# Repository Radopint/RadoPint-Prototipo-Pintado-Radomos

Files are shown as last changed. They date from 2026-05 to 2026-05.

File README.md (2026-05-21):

# RadoPint - Prototipo a escala para pintado de radomos aeronáuticos

Este repositorio contiene los archivos desarrollados para el trabajo de grado
"Prototipo a escala para el proceso de pintado de radomos aeronáuticos (RadoPint)".

## Contenido del repositorio

- `matlab/`: scripts para procesamiento del perfil del radomo, generación de trayectorias y conversión a G-code.
- `gcode/`: archivos G-code generados para pruebas en seco, calibración y aplicación de pintura.
- `esp32_sensores/`: código de la ESP32 para lectura del sensor VL53L0X y microswitches de seguridad.
- `marlin/`: configuración modificada de Marlin para el prototipo.
- `cad_planos/`: planos, archivos CAD, STL y STEP del sistema mecánico.
- `pruebas/`: protocolo de pruebas, datos experimentales y resultados de medición.
- `documentacion/`: manual de usuario y manual de desarrollador.

## Software requerido

- MATLAB
- Arduino IDE
- Marlin
- Pronterface
- SolidWorks o visor CAD compatible

## Versión documentada

Versión: v1.0  
Fecha: mayo de 2026  
Uso: Trabajo de grado - Pontificia Universidad Javeriana

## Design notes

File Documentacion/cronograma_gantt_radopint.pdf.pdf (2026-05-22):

# RADOPINT

RESPONSABLE DEL PROYECTO | ANDRÉS FELIPE RAMÍREZ | FECHA | 21/05/26
| ANDRÉS FELIPE PÉREZ
| JULIAN DAVID AREVALO
2025 | 2026
FASE | DETALLES | T1 | T2 | T2 | T3 | T4
JUL | AGO | SEP | OCT | NOV | DIC | ENE | FEB | MAR | ABR | MAY | JUN SEMANA DEL PROYECTO: | Introduce la fecha del primer
lunes de cada mes --> | 1 | 7 | 14 21 28 | 1 | 7 | 14 21 28 | 1 | 7 | 14 21 28 | 1 | 7 | 14 21 28 | 1 | 7 | 14 21 28 | 1 | 7 | 14 21 28 | 1 | 7 | 14 21 28 | 1 | 7 | 14 21 28 | 1 | 7 | 14 21 28 | 1 | 7 | 14 21 28 | 1 | 7 | 14 21 28 | 1 | 7 | 14 21 28
1 | Concepción inicial del proyecto
- Identificación de la problemática del repintado manual

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
- Justificación técnica de la automatización
- Revisión inicial de literatura
- Revisión de normativas aeronáuticas
- Primer alcance del proyecto
- Reuniones iniciales con los directores
- Definición preliminar del radomo, pintura y proceso

## 2 Estado del arte y análisis técnico

- Búsqueda detallada de artículos, patentes y estándares
- Comparación entre métodos manuales vs automatizados
- Estudio de robótica de aspersión
- Estudio de CFD y modelos de atomización
- Revisión de sensores de espesor
- Construcción del estado del arte completo
- Redacción del marco teórico

## 3 Definición formal del proyecto

- Definición del objetivo general y específicos
- Redacción de requerimientos funcionales
- Requerimientos no funcionales y de seguridad
- Definición de la arquitectura general del sistema
- Diseño del diagrama de bloques
- Identificación de riesgos y limitaciones
- Revisión con directores y ajustes

## 4 Planeación inicial y Documento de Concepción

- Elaboración de la EDT / WBS
- Construcción del cronograma preliminar
- Estimación de recursos y presupuesto
- Análisis normativo final
- Impactos ambientales y socioeconómicos
- Redacción del documento de concepción
- Revisión con directores final
| Entrega del Documento de Concepción - Cierre de Seminario de TG
5 | Diseño y modelado del efector final
- Definición de parámetros de pintura
- Modelado CAD detallado
- Revisión inicial de literatura
- Generación de trayectorias simuladas
- Simulación DPM / espesor / eficiencia de transferencia
- Integración del efector con el prototipo
- Ajustes finales del diseño

## 6 Construcción de la plataforma

- Diseño mecánico final (plataforma con 4 DOF)
- Selección de motores, reductores y sensores
- Diseño del sistema de dosificación
- Fabricación (impresión 3D, CNC, etc.)
- Ensamble estructural completo
- Pruebas de movimiento y calibración

## 7 Sistema de control y adquisición

- Diseño del esquema eléctrico
- Programación del microcontrolador/PLC
- Integración de sensores y actuadores
- Desarrollo de la interfaz de usuario
- Pruebas funcionales del sistema completo

8

## Evaluación y validación experimental

- Diseño del plan de pruebas
- Pruebas de aplicación de pintura
- Medición de espesor y uniformidad
- Ajustes mecánicos, eléctricos y de trayectoria

## 7 Documentación, videos y defensa

- Redacción del informe final
- Elaboración del manual de operación
- Construcción de figuras, tablas y anexos
- Preparación de la presentación final
- Ensayo general

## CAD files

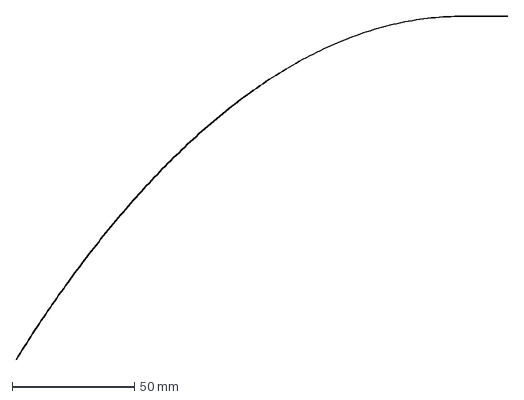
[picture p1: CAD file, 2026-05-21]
Matlab/radomo.DXF
201.4 x 140.7 mm

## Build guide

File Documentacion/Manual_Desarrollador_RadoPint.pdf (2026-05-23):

Manual de desarrollador - RadoPint | Página 1

# Manual de desarrollador

## Prototipo a escala para el proceso de pintado de radomos aeronáuticos RadoPint

Campo | Información
Proyecto | RadoPint - Prototipo a escala para aplicación automatizada de pintura sobre radomos aeronáuticos
Autores | Andrés Felipe Pérez Díaz, Julián David Arévalo Carrero, Andrés Felipe Ramírez Quintero
Director | Francisco Carlos Calderón Bocanegra, Ph.D.
Co-director | Jairo Roa León, Ph.D.
Institución | Pontificia Universidad Javeriana - Facultad de Ingeniería
Versión del manual | v1.0 - mayo de 2026

Este manual está dirigido a estudiantes, investigadores o desarrolladores que requieran modificar, mantener, calibrar o extender el prototipo RadoPint. No sustituye el manual de usuario; lo complementa con información técnica sobre la estructura de software, firmware, trayectorias, sensado, seguridad y control.

Advertencia: RadoPint es un prototipo académico a escala. No está certificado para uso industrial ni para mantenimiento aeronáutico real. Cualquier modificación debe validarse primero con pruebas en seco y con el sistema de dispersión desactivado.

# Contenido

### - 1. Alcance y responsabilidades del desarrollador

### - 2. Arquitectura técnica del prototipo

### - 3. Repositorio y organización de archivos

### - 4. Flujo de desarrollo de trayectorias

### - 5. Mapeo de ejes y convenciones de movimiento

### - 6. Scripts de MATLAB

### - 7. Generación y revisión de G-code

### - 8. Firmware Marlin y configuración de control

### - 9. Sistema de sensado y seguridad con ESP32

### - 10. Parámetros de calibración

### - 11. Protocolo de modificación y pruebas

### - 12. Depuración de fallas frecuentes

### - 13. Buenas prácticas de documentación

### - 14. Lista de verificación para nuevas versiones

# 1. Alcance y responsabilidades del desarrollador

El manual de desarrollador describe cómo está organizado el sistema técnico de RadoPint y qué criterios deben respetarse al modificar códigos, firmware, archivos G-code, sensores o parámetros de calibración. El prototipo utiliza una arquitectura dividida en dos niveles: el cálculo externo de trayectorias en MATLAB y la ejecución física mediante Marlin sobre Arduino Mega 2560 y RAMPS 1.4. Esta separación permite que los cálculos geométricos se realicen fuera del microcontrolador y que el sistema embebido se concentre en ejecutar movimiento, activar salidas auxiliares y coordinar actuadores.

# Responsabilidades mínimas del desarrollador

- Conservar la trazabilidad de cada cambio realizado en MATLAB, Marlin, ESP32 o G-code.
- Probar cualquier modificación primero con archivo de prueba en seco, sin pintura y con la electroválvula desactivada.
- Verificar que los comandos de movimiento no excedan los límites físicos de los ejes X, Y, Z y E.
- Mantener separado el código de seguridad de la ESP32 y el firmware de movimiento de Marlin.
- Actualizar el repositorio, el README y las tablas de anexos cuando se agreguen archivos o versiones nuevas.

# Límites del manual

Este documento no explica la operación básica paso a paso para usuarios finales. Para encendido, homing, carga de G-code y apagado seguro debe consultarse el manual de usuario. El presente manual se enfoca en modificación, mantenimiento técnico, calibración y extensión del sistema.

# 2. Arquitectura técnica del prototipo

RadoPint integra una plataforma tipo pórtico para posicionar un aerógrafo frente a un radomo a escala. La arquitectura combina subsistemas mecánicos, electrónicos, neumáticos, de control y de seguridad. Desde el punto de vista de desarrollo, los bloques más relevantes son el generador de trayectorias en MATLAB, el firmware Marlin, la electrónica Arduino Mega/RAMPS, los drivers de motores, la ESP32 de seguridad y los archivos G-code de ejecución.

Subsistema | Elemento principal | Función técnica
Planificación | MATLAB | Procesa el perfil DXF del radomo, calcula anillos, posición del aerógrafo, orientación y velocidad de giro.
Ejecución | Marlin + Arduino Mega + RAMPS 1.4 | Interpreta G-code, coordina motores paso a paso y activa salidas auxiliares.
Movimiento | DRV8825 y DM556 | Controlan motores NEMA 17 y NEMA 34 según el eje correspondiente.
Dispersión | Aerógrafo, compresor, regulador y electroválvula | Habilita o interrumpe el flujo de aire/material durante los anillos de aplicación.
Seguridad | ESP32, VL53L0X, microswitches y botón de emergencia | Supervisa proximidad y condiciones de seguridad durante operación y calibración.
Validación | HW300PRO y testigos metálicos | Permite evaluar el espesor de recubrimiento aplicado sobre sustrato metálico.

La nomenclatura de ejes del firmware se adaptó a la arquitectura real del prototipo: X corresponde al desplazamiento horizontal del aerógrafo, Y al desplazamiento vertical, Z al giro angular del aerógrafo y E al giro directo de la plataforma del radomo. En esta configuración, E no representa extrusión, sino rotación controlada del radomo mediante un motor NEMA 34.

# 3. Repositorio y organización de archivos

El repositorio digital centraliza los archivos necesarios para reproducir la versión documentada del prototipo. Se recomienda trabajar siempre sobre una copia local, crear una rama o carpeta de pruebas para modificaciones y subir solo versiones verificadas.

### Repositorio: https://github.com/Radopint/RadoPint-Prototipo-Pintado-Radomos

Carpeta / archivo | Contenido | Uso del desarrollador
Matlab/ | Scripts de procesamiento del perfil, generación de anillos, trayectorias y archivos de verificación. | Modificar parámetros geométricos, velocidades, solapamiento, distancia y mapeo a G-code.
G-code/ | Archivos dry-run, calibración y pintura. | Ejecutar pruebas, validar comandos y conservar versiones de trayectorias.
Marlin/ | Configuration.h, Configuration_adv.h, Marlin.ino, Version.h, Makefile y config.ini. | Ajustar pasos por unidad, límites, velocidades, aceleraciones y pines.
esp32_sensores/ | Código Sensores.ino y librerías asociadas. | Modificar umbrales de seguridad, lectura de VL53L0X y microswitches.
Pruebas/ | Protocolos de pruebas y registros experimentales. | Documentar validaciones de movimiento, dispersión, sensores e integración.
Documentacion/ | Manual de usuario, manual de desarrollador e instrucciones complementarias. | Actualizar manuales y versiones entregables.
cad_planos/ | Planos, STL, STEP y ensamble general, si están disponibles. | Respaldar cambios mecánicos y nuevas piezas.

# Convención recomendada de nombres

radome_spray_model_RadoPint_vX_Y.m radome_generate_marlin_RadoPint_vX_Y.m radome_ring_schedule_vX_Y.csv radome_command_check_vX_Y.csv RadoPint_DRYRUN_vX_Y.gcode RadoPint_PAINT_vX_Y.gcode
RadoPint_CALIBRATE_DISTANCE_vX_Y.gcode

# 4. Flujo de desarrollo de trayectorias

El flujo técnico de desarrollo inicia con el perfil geométrico del radomo y termina con la ejecución física en el prototipo. El desarrollador debe conservar los archivos intermedios para poder rastrear de dónde proviene cada comando enviado a la máquina.

Paso | Entrada | Proceso | Salida
1 | Perfil DXF del radomo | Lectura y ordenamiento de entidades geométricas | Perfil procesado CSV
2 | Perfil procesado | Discretización por longitud meridiana y anillos | radome_ring_schedule.csv
3 | Tabla de anillos | Cálculo de posiciones X, Y, Z y velocidad E | radome_command_check.csv
4 | Comandos verificados | Escritura de G-code | Dry-run, paint y calibración
5 | G-code | Envío por Pronterface a Marlin | Movimiento físico y activación de electroválvula

Antes de ejecutar el archivo de pintura, se debe ejecutar el archivo de prueba en seco. Solo cuando el recorrido no genera colisiones, activaciones de seguridad o errores de distancia, se habilita la electroválvula y se realiza la aplicación real.

# 5. Mapeo de ejes y convenciones de movimiento

Eje Marlin | Función en RadoPint | Actuador | Observaciones de desarrollo
X | Desplazamiento horizontal/radial del aerógrafo | NEMA 17 + DRV8825 | Controla aproximación a la superficie. Verificar límites antes de acercar al radomo.
Y | Desplazamiento vertical | NEMA 34 + DM556 | Eje de mayor carga. En la máquina puede operar con convención invertida respecto al movimiento físico.
Z | Giro angular del aerógrafo | NEMA 17 + DRV8825 | Ajusta orientación del chorro. Limitar ángulos para evitar interferencias y disparos del sensor.
E | Giro directo de la plataforma del radomo | NEMA 34 + DM556 | No es extrusión. Debe mantenerse en modo compatible con movimiento continuo controlado.

# Comandos de referencia

G21 | ; unidades en mm
G90 | ; coordenadas absolutas para X, Y, Z
M82 | ; eje E en modo absoluto
M17 | ; habilitar motores
M302 P1 | ; permitir movimiento de E sin control de temperatura
G92 X0 Y200 Z200 E0 | ; referencia inicial del programa

La posición inicial recomendada para ejecución de trayectorias es X=0, Y=200, Z=200 y E=0, con el aerógrafo en la zona inferior del radomo y orientado de frente. Si se modifica esta referencia, debe actualizarse el generador de G-code y el procedimiento de homing/calibración.

# 6. Scripts de MATLAB

Los scripts de MATLAB son responsables de convertir la geometría del radomo en una trayectoria discreta por anillos y luego en comandos G-code. El primer script procesa el DXF y genera la tabla de anillos. El segundo convierte la tabla en archivos ejecutables por Marlin.

Función / archivo | Propósito | Puntos que puede modificar el desarrollador
readProfileFromDXF | Lee el perfil del radomo desde el DXF. | Ruta del archivo DXF, unidades, inversión o limpieza de coordenadas.
readDXFLines | Extrae entidades tipo línea. | Tolerancia de lectura y filtrado de entidades no deseadas.
removeDuplicateSegmen ts | Elimina segmentos repetidos. | Criterio de tolerancia para duplicados.
orderOpenPolyline | Ordena segmentos en una polilínea abierta. | Sentido de recorrido y validación de continuidad.
radome_ring_schedule.cs v | Tabla de anillos con posición, ángulo, velocidad, vueltas y tiempo. | Número de anillos, solapamiento, diámetro de patrón y velocidad.
generate_marlin...m | Convierte anillos en comandos Marlin. | Mapeo de X/Y/Z/E, velocidades, electroválvula, pausas y límites.

# Parámetros críticos

- Diámetro del patrón de aspersión: determina separación entre anillos junto con el solapamiento.
- Solapamiento: controla continuidad de cobertura entre anillos sucesivos.
- Distancia de trabajo: define separación boquilla-superficie usada en cálculo de posición.
- Ganancia angular de Z: limita la inclinación física del aerógrafo respecto a la geometría ideal.
- E_UNITS_PER_REV: relación entre unidades del eje E y una vuelta física del radomo. Debe calibrarse antes de generar G-code final.
- Velocidad mínima y máxima del radomo: evita movimientos demasiado lentos o pérdida de pasos.

Regla práctica: cada vez que se cambie un parámetro geométrico, de velocidad o de eje, se debe regenerar la tabla de anillos y el archivo command_check antes de crear el G-code final.

# 7. Generación y revisión de G-code

El G-code generado debe conservar una secuencia segura por anillo: primero posicionar el aerógrafo, luego activar la electroválvula, después girar el radomo y finalmente apagar la electroválvula antes de pasar al siguiente anillo. Esta lógica evita pulverizar durante movimientos de reposicionamiento.

# Estructura recomendada por anillo

; --- Anillo i ---
G1 X... Y... Z... F... | ; posicionar aerógrafo sin pintura
G4 P... | ; pausa corta opcional para estabilizar
M42 P5 T1 S255 | ; activar electroválvula / aire
G1 E... F... | ; giro del radomo una vuelta o fracción programada
M42 P5 T1 S0 | ; desactivar electroválvula
G4 P... | ; pausa opcional antes del siguiente anillo
Archivo | Uso | Regla de seguridad
DRYRUN | Verificar recorrido sin pintura. | Debe ejecutarse antes de PAINT.
PAINT | Aplicación real con electroválvula. | Ejecutar solo con compresor regulado, distancia validada y zona despejada.
CALIBRATE_DISTANCE | Posicionar en anillos y medir distancia manualmente. | Usar con electroválvula apagada.
command_check.csv | Revisión tabular de comandos. | No ejecutar si hay valores fuera de límites.

# Criterios de rechazo de un G-code

- El primer comando no parte de la referencia inicial establecida.
- Algún valor X, Y o Z excede límites físicos o software.
- E no corresponde a la relación de unidades por vuelta calibrada.
- La electroválvula se activa durante movimientos de reposicionamiento.
- No existe comando de apagado M42 P5 T1 S0 al final de cada segmento de aplicación.

# 8. Firmware Marlin y configuración de control

Marlin se utiliza como firmware de ejecución por su capacidad para interpretar G-code, manejar motores paso a paso, configurar parámetros dinámicos y activar salidas digitales. El desarrollador debe modificar Marlin con cuidado, ya que cambios en pasos por unidad, aceleraciones o límites pueden producir pérdida de pasos, colisiones o trayectorias incorrectas.

Archivo | Función | Parámetros típicos que se revisan
Configuration.h | Configuración principal del firmware. | Tarjeta, pasos por unidad, límites, velocidades máximas, aceleraciones, finales de carrera.
Configuration_adv.h | Configuración avanzada. | Comportamiento dinámico, funciones adicionales, ajustes de movimiento.
Marlin.ino | Archivo principal para abrir el firmware en Arduino IDE. | No se recomienda modificar salvo que sea necesario.
Version.h | Información de versión base. | Sirve para trazabilidad del firmware utilizado.
Makefile / config.ini | Archivos auxiliares de compilación. | Conservar para mantener la estructura del proyecto.

# Buenas prácticas al modificar Marlin

1 Duplicar la carpeta Marlin antes de modificarla.

2 | Anotar en README la razón del cambio y la fecha.
3 | Compilar antes de cargar a la tarjeta.
4 | Probar movimiento eje por eje con desplazamientos pequeños.
5 | Verificar que los microswitches de homing siguen respondiendo.
6 | Ejecutar un dry-run completo antes de usar pintura.

No se recomienda cambiar simultáneamente pasos por unidad, límites y aceleraciones. Modifique un parámetro a la vez y registre el resultado experimental.

# 9. Sistema de sensado y seguridad con ESP32

El sistema de seguridad se separó del firmware de movimiento. Los microswitches de homing se conectan a RAMPS para establecer referencias de posición, mientras que los sensores de seguridad se gestionan mediante la ESP32. Esta separación evita sobrecargar Marlin con lectura continua de sensores adicionales y permite implementar una capa auxiliar de protección.

Elemento | Ubicación lógica | Función
VL53L0X | ESP32 | Medir distancia entre aerógrafo/radomo y detectar aproximaciones peligrosas.
Microswitches de seguridad | ESP32 | Detectar límites o condiciones de protección independientes del homing.
Microswitches de homing | RAMPS | Referenciar ejes antes de ejecutar trayectorias.
Botón de emergencia | Circuito de seguridad | Permitir intervención manual ante comportamiento inesperado.
Señal de alerta | ESP32 hacia sistema principal | Detener o impedir continuidad del movimiento ante condición insegura.

# Puntos de ajuste del código ESP32

- Umbral mínimo de distancia permitido por el VL53L0X.
- Lógica de lectura de microswitches: normalmente abierto o normalmente cerrado.
- Tiempo de filtrado o antirrebote para entradas digitales.
- Estado seguro por defecto ante pérdida de lectura del sensor.
- Pin de salida de alerta hacia el sistema principal.

Toda modificación en umbrales de seguridad debe probarse con el sistema sin pintura y con movimientos lentos. Si el sensor falla, el estado por defecto debe ser seguro, no permisivo.

# 10. Parámetros de calibración

La calibración conecta el modelo computacional con el comportamiento real del prototipo. Debe repetirse cuando se cambie un motor, driver, husillo, soporte mecánico, aerógrafo, radomo, distancia de trabajo o versión del firmware.

Parámetro | Cómo se calibra | Qué afecta
X radial | Mover en incrementos pequeños y medir distancia boquilla-radomo. | Distancia de aplicación y riesgo de colisión.
Y vertical | Verificar recorrido desde base hasta zona superior del radomo. | Cobertura de anillos y altura de aplicación.
Z angular | Comparar comando con ángulo físico del aerógrafo. | Orientación del chorro y activación del sensor de distancia.
E_UNITS_PER_REV | Mandar un movimiento conocido de E y contar vueltas reales del radomo. | Número de vueltas por anillo y velocidad angular real.

Parámetro | Cómo se calibra | Qué afecta
Velocidad E | Ejecutar anillos de prueba y verificar continuidad sin pérdida de pasos. | Tiempo de aplicación y espesor depositado.
Electroválvula | Activar con M42 y verificar apertura/cierre sin retrasos excesivos. | Inicio y fin de pulverización.
Distancia de trabajo | Usar G-code de calibración y medición manual/sensor. | Uniformidad de patrón y repetibilidad.

# Comandos útiles para calibración

M114 | ; leer posición actual reportada por Marlin
G1 X10 F300 | ; mover X lentamente
G1 Y190 F200 | ; mover Y lentamente
G1 Z190 F120 | ; ajustar ángulo del aerógrafo
G1 E5 F60 | ; probar giro del radomo según calibración
M42 P5 T1 S255 | ; activar electroválvula
M42 P5 T1 S0 | ; desactivar electroválvula

# 11. Protocolo de modificación y pruebas

Cada cambio técnico debe pasar por una validación escalonada. Esto reduce el riesgo de daños mecánicos, pérdida de pasos, activación inesperada de la electroválvula o colisiones con el radomo.

1 | Registrar el cambio propuesto: archivo, parámetro, motivo y valor anterior/nuevo.
2 | Compilar o ejecutar el código modificado sin conectar pintura.
3 | Revisar archivos CSV intermedios y command_check.
4 | Ejecutar movimiento manual eje por eje.
5 | Ejecutar G-code de calibración de distancia.
6 | Ejecutar dry-run completo con electroválvula apagada.
7 | Ejecutar prueba de electroválvula sin pintura.
8 | Ejecutar aplicación con agua o pintura diluida sobre superficie de ensayo.
9 | Ejecutar aplicación final sobre radomo/testigos.
10 | Registrar resultados, fotos, versión de archivos y observaciones.

# Formato mínimo de registro

Campo | Descripción
Fecha | Día de la prueba o cambio.
Versión | Versión de MATLAB, G-code, Marlin y ESP32 utilizada.
Cambio | Descripción corta del parámetro o archivo modificado.
Resultado | Aprobado, rechazado o requiere ajuste.
Evidencia | Fotos, video, CSV, mediciones o captura de Pronterface.

# 12. Depuración de fallas frecuentes

Falla | Causa probable | Acción recomendada
Un eje se mueve al revés | Convención física distinta a Marlin o cableado de bobinas invertido. | Corregir en firmware, generador de G-code o cableado. Probar eje individual antes de ejecutar trayectoria.
El aerógrafo se acerca demasiado | Mapeo X incorrecto, rampa de X muy agresiva o distancia base mal calibrada. | Ejecutar G-code de calibración, medir distancia por anillo y ajustar parámetros de X.

Falla | Causa probable | Acción recomendada
El ángulo Z se posiciona durante el pintado | Velocidad/aceleración del eje Z insuficiente o comando combinado no espera finalización esperada. | Separar posicionamiento de Z antes de activar electroválvula; reducir velocidad de aplicación hasta confirmar.
El radomo gira lento o rápido | E_UNITS_PER_REV o F de eje E mal calibrado. | Repetir prueba de vueltas con G1 E... y recalcular relación.
La electroválvula queda activada | MOSFET mal cableado, pin en estado flotante o falta de apagado M42. | Verificar resistencia de pull-down, diodo de rueda libre, comando M42 P5 T1 S0 y cableado.
Activación del sensor de distancia | Boquilla demasiado cerca, orientación incorrecta o soporte vibrando. | Detener, alejar X, revisar Z y repetir dry-run.
Pérdida de pasos | Aceleración alta, corriente insuficiente, carga excesiva o atasco mecánico. | Reducir aceleración/velocidad, revisar driver, lubricación y alineación.

# 13. Buenas prácticas de documentación

La documentación técnica es parte del prototipo. Sin trazabilidad, no es posible reproducir una trayectoria ni defender resultados experimentales. Por ello, cada versión funcional debe tener código, parámetros, G-code y evidencia asociados.

- Crear una etiqueta de versión cuando se cierre una entrega importante, por ejemplo v1.0.
- Guardar el G-code exacto ejecutado en cada prueba, no solo el script que lo genera.
- No sobrescribir tablas CSV de resultados sin respaldo.
- Subir al repositorio solo archivos que no contengan datos sensibles o credenciales.
- Mantener un README por carpeta cuando el contenido no sea evidente.
- Registrar cambios de firmware en un archivo CHANGELOG.md.

# Estructura sugerida de CHANGELOG

## v1.1 - AAAA-MM-DD

- Cambio: ajuste de E_UNITS_PER_REV de ... a ...
- Motivo: prueba de rotación mostró ...
- Archivos modificados: generate_marlin..., Configuration.h
- Validación: dry-run completo aprobado / pendiente
- Responsable: nombre del desarrollador

# 14. Lista de verificación para nuevas versiones

Ítem | Verificación | Estado
1 | El repositorio contiene la versión final de MATLAB, Marlin, ESP32 y G-code.
2 | El README describe carpetas, software requerido y secuencia de uso.
3 | El mapeo de ejes X/Y/Z/E coincide entre MATLAB, G-code, Marlin y documento.
4 | El archivo command_check fue revisado antes de ejecutar PAINT.
5 | Dry-run completo ejecutado sin colisiones ni alarmas.
6 | Electroválvula probada con M42 encendido/apagado.
7 | ESP32 detecta VL53L0X y microswitches de seguridad.
8 | Homing manual o automático validado antes de trayectoria.
9 | Prueba de distancia boquilla-radomo realizada en anillos críticos.
10 | Datos experimentales guardados con fecha, versión y observaciones.

# Cierre

El propósito de este manual es permitir que RadoPint pueda mantenerse y evolucionar de forma controlada. Cualquier cambio debe preservar la seguridad del operador, la integridad de la estructura y la trazabilidad de los resultados experimentales.

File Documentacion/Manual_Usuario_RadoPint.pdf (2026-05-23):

Manual de usuario - RadoPint | Prototipo experimental a escala

# Manual de usuario

# RadoPint

## Prototipo a escala para el proceso de pintado de radomos aeronáuticos

Alcance: Este manual describe la operación del prototipo RadoPint en entorno de laboratorio. El sistema no está certificado para uso aeronáutico real ni para mantenimiento industrial.

Autores: Andrés Felipe Pérez Díaz, Julián David Arévalo Carrero, Andrés Felipe Ramírez Quintero

Pontificia Universidad Javeriana - Facultad de Ingeniería

Versión del manual: 1.0 | Fecha: mayo de 2026

# Contenido del manual

- 1. Propósito y alcance
- 2. Descripción general del prototipo
- 3. Seguridad antes de operar
- 4. Identificación de ejes y archivos de operación
- 5. Preparación antes de la prueba
- 6. Encendido, conexión y verificación inicial
- 7. Calibración y prueba en seco
- 8. Ejecución de aplicación de pintura
- 9. Medición de espesor y registro de datos
- 10. Apagado, limpieza y mantenimiento
- 11. Solución de problemas frecuentes
- 12. Lista rápida de verificación

# 1. Propósito y alcance

Este manual tiene como propósito guiar al usuario en la preparación, operación, supervisión y apagado seguro del prototipo RadoPint. El documento está dirigido a operadores, estudiantes o investigadores que deban ejecutar pruebas de trayectoria, aplicación de pintura o medición de espesor sobre el sistema.

RadoPint es un prototipo experimental a escala diseñado para aplicar pintura sobre un modelo de radomo mediante una plataforma de posicionamiento, un aerógrafo, una plataforma rotativa y una electrónica de control basada en Arduino Mega, RAMPS 1.4 y firmware Marlin. La operación debe realizarse únicamente bajo supervisión y en un entorno de laboratorio.

Importante: El prototipo no debe utilizarse como equipo certificado de mantenimiento aeronáutico. Las pruebas descritas corresponden a validación experimental y académica.

# 2. Descripción general del prototipo

El sistema integra subsistemas mecánicos, electrónicos, de control, sensado, seguridad y dispersión. La estación externa de supervisión genera o envía archivos G-code, mientras que Marlin interpreta las instrucciones y coordina los ejes, el giro del radomo y la electroválvula.

Subsistema | Elementos principales | Función
Movimiento | Motores NEMA 17, motores NEMA 34, drivers DRV8825 y DM556, guías y husillos | Posicionar el aerógrafo y girar la plataforma del radomo.
Control central | Arduino Mega 2560, RAMPS 1.4 y firmware Marlin | Interpretar G-code, controlar motores y activar salidas auxiliares.
Seguridad | ESP32, VL53L0X, microswitches de seguridad y botón de emergencia | Supervisar proximidad, límites y condiciones inseguras.
Dispersión | Compresor, regulador, electroválvula, mangueras y aerógrafo Paasche VL | Atomizar y aplicar pintura durante los segmentos programados.
Medición | Sensor de espesor HW300PRO y testigos de acero inoxidable | Registrar espesor del sistema de recubrimiento después de la aplicación.

# 3. Seguridad antes de operar

Antes de operar el prototipo, el usuario debe verificar que las condiciones eléctricas, mecánicas y neumáticas sean seguras. El sistema incluye capas de protección, pero estas no reemplazan la supervisión directa del operador.

Riesgo | Medida preventiva

Movimiento inesperado de ejes | Mantener manos, herramientas y cables fuera del volumen de trabajo. Ejecutar primero una prueba en seco.
Colisión del aerógrafo con el radomo | Verificar sensor VL53L0X, microswitches de seguridad y trayectoria antes de activar pintura.
Activación no deseada de pintura o aire | Mantener la electroválvula apagada durante posicionamientos y pruebas de movimiento.
Presión de aire | Revisar regulador, mangueras y conexiones antes de abrir el compresor. No superar la presión definida para la prueba.
Riesgo eléctrico | No manipular conexiones con las fuentes encendidas. Separar control, potencia y cargas inductivas.
Aerosoles y pintura | Usar gafas, guantes, tapabocas o respirador, y trabajar en zona ventilada.

Parada de emergencia: Si se observa vibración excesiva, pérdida de pasos, acercamiento peligroso, fuga de aire, activación inesperada de la válvula o trayectoria incorrecta, presione el botón de parada de emergencia y corte la alimentación si es necesario.

## 3.1. Función de los sensores de seguridad

El prototipo diferencia los microswitches de homing y los sensores de protección. Los microswitches de homing están conectados a la RAMPS para establecer referencias de posición. Los microswitches de seguridad y el sensor VL53L0X son gestionados por una ESP32, la cual envía una señal de alarma al sistema principal si detecta una condición insegura.

La señal de seguridad se implementa como una línea física de parada entre la ESP32 y el Arduino Mega/RAMPS. La comunicación serial de la ESP32 se utiliza únicamente para monitoreo y depuración del estado de sensores.

# 4. Identificación de ejes y archivos de operación

Eje en Marlin | Función física en RadoPint | Observación operativa
X | Desplazamiento horizontal/radial del aerógrafo | Ajusta la distancia entre boquilla y radomo.
Y | Desplazamiento vertical del aerógrafo | Permite avanzar desde la base hacia la parte superior del radomo.
Z | Giro angular del aerógrafo | Orienta el chorro hacia la superficie curva.
E | Giro directo de la plataforma del radomo | No representa extrusión; controla la rotación del radomo mediante NEMA 34.
Tipo de archivo | Uso recomendado
DRYRUN / prueba en seco | Verificar movimiento completo sin activar la electroválvula ni aplicar pintura.
CALIBRATE_DISTANCE | Posicionar el aerógrafo por anillos y hacer pausas para medir o ajustar distancia.
PAINT / aplicación | Ejecutar la trayectoria final con activación sincronizada de la electroválvula.
command_check.csv | Revisar posiciones, velocidades y comandos antes de ejecutar el G-code.

# 5. Preparación antes de la prueba

Realice la preparación con el sistema apagado, sin presión en la línea neumática y con el aerógrafo sin pintura hasta terminar las verificaciones iniciales.

1. Verificar que el radomo o pieza de ensayo esté centrado sobre la plataforma rotativa.
2. Confirmar que no existan obstáculos en el recorrido de los ejes X, Y, Z y E.
3. Revisar que las mangueras de aire no interfieran con el movimiento del aerógrafo.
4. Verificar conexiones de motores, drivers, RAMPS, ESP32, sensores y electroválvula.
5. Confirmar que el botón de emergencia esté accesible para el operador.
6. Preparar el archivo G-code correcto según la etapa: calibración, prueba en seco o aplicación.
7. Si se va a medir espesor, ubicar testigos de acero inoxidable y registrar su identificación.

Cambio asistido de aplicador: Si se requiere cambiar el aerógrafo o pistola, el sistema debe estar detenido. El cambio asistido corresponde a una operación manual guiada por el operario sobre el soporte modular del efector final.

# 6. Encendido, conexión y verificación inicial

Paso | Acción | Resultado esperado
1 | Verificar que el botón de emergencia esté liberado y que no haya alarmas activas. | El sistema queda listo para energizar.
2 | Conectar la alimentación de control y potencia según la configuración del prototipo. | Arduino/RAMPS, drivers y ESP32 energizados.
3 | Conectar el cable USB entre el computador y Arduino Mega. | El puerto serial queda disponible.
4 | Abrir Pronterface y seleccionar el puerto serial correspondiente. | Conexión estable con Marlin.
5 | Enviar un comando simple de consulta o movimiento pequeño. | Respuesta correcta del firmware sin errores.
6 | Probar sensores de seguridad sin iniciar una trayectoria. | La alerta se activa y se restablece según corresponda.

## 6.1. Homing y referencia inicial

Antes de ejecutar una trayectoria, establezca una referencia de posición. El homing puede realizarse desde Pronterface o mediante comandos G-code, según la configuración cargada en Marlin. No ejecute archivos de aplicación sin haber verificado previamente la posición inicial del sistema.

En la configuración usada durante las pruebas, la trayectoria parte de una condición inicial de referencia en la que el aerógrafo está ubicado frente a la parte baja del radomo y la plataforma se encuentra lista para iniciar el giro. Verifique que los valores iniciales de X, Y, Z y E coincidan con el archivo G-code generado.

# 7. Calibración y prueba en seco

La calibración debe realizarse antes de toda prueba con pintura. El objetivo es confirmar que el aerógrafo sigue el perfil del radomo, mantiene una distancia segura y que el eje E gira la plataforma sin interferencias.

Etapa | Procedimiento | Criterio de aceptación
Calibración de distancia | Ejecutar el archivo CALIBRATE_DISTANCE y verificar la separación boquilla-radomo en cada anillo. | No hay contacto ni activación de alarma por proximidad.
Prueba en seco | Ejecutar el archivo DRYRUN sin pintura y sin activación de la válvula. | La trayectoria completa se ejecuta sin colisiones.
Verificación angular | Observar el giro del aerógrafo durante el ascenso por anillos. | El chorro quedaría orientado hacia la superficie sin apuntar fuera del radomo.
Verificación del eje E | Confirmar que el radomo complete la rotación requerida por anillo. | El giro es estable y no hay pérdida evidente de pasos.

Ajuste recomendado: Si la distancia disminuye demasiado en los primeros anillos o el aerógrafo apunta fuera de la superficie, no compense manualmente durante la aplicación. Detenga el proceso, ajuste los parámetros del generador de G-code y repita la prueba en seco.

# 8. Ejecución de aplicación de pintura

Cuando la trayectoria en seco haya sido validada, se puede realizar la aplicación de pintura. El operador debe mantener supervisión continua durante todo el proceso.

8. Preparar la pintura según la dilución definida para la prueba y cargar el aerógrafo.

9. Encender el compresor y ajustar el regulador a la presión de trabajo definida experimentalmente.
10. Realizar una prueba de atomización fuera del radomo o sobre una superficie auxiliar.
11. Confirmar que la electroválvula esté apagada antes de posicionar el aerógrafo.
12. Cargar en Pronterface el archivo G-code de aplicación con pintura.
13. Iniciar la ejecución y observar el primer anillo completo antes de dejar continuar la rutina.
14. Detener inmediatamente el proceso si se activa una alarma, se observa goteo, hay pérdida de pasos o cambia la distancia de forma peligrosa.

Lógica de dispersión: La electroválvula debe activarse únicamente durante el giro controlado del radomo y permanecer apagada durante los reposicionamientos del aerógrafo entre anillos.

## 8.1. Condiciones para detener la prueba

- La boquilla o soporte se aproxima demasiado al radomo.
- El sensor VL53L0X o un microswitch de seguridad activa alarma.
- El radomo pierde centrado o presenta vibración anormal.
- La electroválvula queda activada cuando no debe.
- El aerógrafo gotea, se obstruye o cambia el patrón de aspersión.
- El operador detecta ruido anormal en drivers, motores o estructura.

# 9. Medición de espesor y registro de datos

El espesor debe medirse sobre testigos de acero inoxidable cuando se utilice el sensor HW300PRO, debido a que este instrumento mide recubrimientos sobre sustratos metálicos mediante inducción. No se debe interpretar una lectura directa sobre el radomo impreso en 3D como una medición válida de espesor por inducción.

Momento | Qué medir | Registro mínimo
Antes de pintar | Espesor base del anticorrosivo sobre cada testigo. | Identificación del anillo, medición base y observaciones.
Después de pintar | Espesor final del sistema de recubrimiento. | Tres mediciones por testigo y promedio local.
Análisis | Espesor neto de pintura. | Diferencia entre medición final y medición base.

Para evaluar únicamente la pintura aplicada por RadoPint, calcule:

## e_pintura = e_final - e_base

El valor final medido no representa únicamente la pintura depositada si el testigo ya tenía una capa de anticorrosivo. Por esta razón, el registro debe conservar siempre la medición antes y después de la aplicación sobre el mismo testigo.

Incertidumbre del HW300PRO: Las lecturas deben interpretarse considerando la exactitud del instrumento. Para valores cercanos a 300 µm, la incertidumbre aproximada del equipo es del orden de ±10 µm, por lo que los resultados son adecuados para validación funcional, no para metrología de alta precisión.

# 10. Apagado, limpieza y mantenimiento

Paso | Acción
1 | Detener la ejecución del G-code y confirmar que la electroválvula esté desactivada.
2 | Cerrar el suministro de aire y liberar presión de las mangueras.
3 | Apagar fuentes de alimentación de potencia y control.
4 | Desconectar USB solo después de detener el firmware y la trayectoria.
5 | Retirar el aerógrafo del soporte modular si se requiere limpieza profunda.

6 | Limpiar el aerógrafo, boquilla, depósito y mangueras según el tipo de pintura usada.
7 | Retirar testigos, etiquetarlos y registrar mediciones.
8 | Inspeccionar cables, conectores, drivers, guías, husillos y soportes antes de almacenar.

## 10.1. Mantenimiento periódico

- Revisar apriete de tornillos, soportes y acoples de motores.
- Verificar alineación de guías lineales y husillos.
- Limpiar residuos de pintura en soporte del aerógrafo, mangueras y base del radomo.
- Revisar conectores de RAMPS, drivers DM556, DRV8825, ESP32 y sensores.
- Comprobar funcionamiento del botón de emergencia y sensores antes de cada jornada.
- Lubricar o limpiar elementos mecánicos de acuerdo con su condición de uso.

# 11. Solución de problemas frecuentes

Problema | Posible causa | Acción recomendada
El sistema no conecta en Pronterface | Puerto incorrecto, cable USB defectuoso o firmware no responde. | Seleccionar puerto correcto, reiniciar Arduino, revisar cable y volver a conectar.
Un eje se mueve en sentido contrario | Configuración de dirección o conexión del motor invertida. | No ejecutar pintura. Corregir en configuración o cableado y repetir prueba en seco.
El aerógrafo se acerca demasiado al radomo | Trayectoria X/Z mal calibrada o radomo descentrado. | Detener, revisar montaje, ejecutar archivo de calibración y ajustar parámetros.
El eje E gira demasiado lento o rápido | Relación de unidades por vuelta o feedrate incorrecto. | Verificar calibración del eje E y archivo command_check.csv.
La electroválvula no activa | Pin incorrecto, etapa MOSFET, alimentación o cableado defectuoso. | Probar con comando manual, revisar fuente, MOSFET, diodo y conexión de bobina.
La electroválvula queda encendida | Falla en MOSFET, señal de control flotante o conexión incorrecta. | Cortar alimentación, revisar etapa de potencia y resistencia de pull-down.
Activación frecuente de seguridad | Distancia menor al umbral, cable suelto o sensor mal posicionado. | Revisar VL53L0X, microswitches y cableado de la ESP32.
Lecturas de espesor inconsistentes | Testigo no metálico, mala calibración del HW300PRO o superficie irregular. | Usar acero inoxidable, recalibrar equipo y realizar tres mediciones por punto.

# 12. Lista rápida de verificación

Ítem | Verificación antes de operar
1 | Área ventilada, limpia y sin obstáculos.
2 | Operador con gafas, guantes y protección respiratoria si aplica.
3 | Radomo centrado y plataforma libre de interferencias.
4 | Mangueras, cables y conectores asegurados.
5 | Botón de emergencia accesible y probado.
6 | Microswitches de homing y seguridad verificados.
7 | Sensor VL53L0X operativo y sin obstrucciones.
8 | Archivo G-code correcto seleccionado.
9 | Prueba en seco ejecutada antes de pintar.
10 | Compresor y regulador ajustados.
11 | Electroválvula probada y apagada antes de iniciar.
12 | Testigos metálicos identificados si se van a medir espesores.
Criterio final: No inicie una aplicación con pintura si no se ha completado exitosamente una prueba en seco con la misma trayectoria.

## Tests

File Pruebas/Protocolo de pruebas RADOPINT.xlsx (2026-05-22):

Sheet: Pruebas de movimiento
SECCIÓN A: Pruebas de movimiento
N° de prueba | Condiciones de la prueba | Camino activado | Secuencia de entradas | Salidas esperadas | Salidas obtenidas
T12 | Prueba del código del microcontrolador - Arduino/PLC | Abrir programa -> subir código → ejecutar | 1. Abrir Pronterface 2. Conectar RAMPS y Arduino 3. Inicializar Gcode y enviar valor de giro 4. Conectar Osciloscopio y medir valor de salida | Las funciones principales responden | Se conecto el Arduino mega con la Ramps y el software Marlin, se envio un comando simulando la conexión de un motor y se midio la salida del driver, el cual dio un funcionamiento correcto
T1 | Prueba básica del motor principal - Motor NEMA 34 | Conectar componentes -> encender arduino -> conectar a marlin→ enviar comando Gcode → detener | 1. Conectar el arduino y colocarle la RAMPS 1.4 (Se alimenta con 12V) 2. Conectar el motor (NEMA 23) al driver DM556 según sus bobinas (El driver se alimenta con 24V) 3. Conectar la salida de las señales de la RAMPS a las entradas negativas del driver ( PLS -, DIR -, EN -) y las salidas positivas a los 5v entregados por el arduino ( PLS -, DIR -, EN -) 4.Conectar la RAMPS a Pronterface teniendo en cuenta el Baud Rate que se configuró en Marlin 5.Enviar comando serial de G-Code desde Pronterface para activar el motor (M17), para configurarlo como coordenadas relativas (G91) y por ultimo para probar un movimiento a una velocidad especificada (ej: G1 Y20 F200) | El motor gira suavemente sin ruidos extraños | Logramos mover el motor a una velocidad de 60 rpm para un movimiento de 20 mm
T2 | Prueba básica del motor secundario - Motor NEMA 17 | Conectar componentes -> encender arduino -> conectar a marlin→ enviar comando Gcode → detener | 1. Conectar el arduino y colocarle la RAMPS 1.4 (Se alimenta con 12V). 2. Conectar el driver (DRV8825) y el motor (NEMA 17) según sus bobinas a la RAMPS. 3.Conectar la RAMPS a Pronterface teniendo en cuenta el Baud Rate que se configuró en Marlin. 4.Enviar comando serial de G-Code desde Pronterface para activar el motor (M17), para configurarlo como coordenadas relativas (G91) y por ultimo para probar un movimiento a una velocidad especificada (ej: G1 Y20 F200). | Responde al comando y gira sin trabarse | Logramos mover el motor a una velocidad de 60 rpm para un movimiento de 50 mm
T3 | Prueba de giro a diferentes velocidades - Motor principal | Conectar componentes -> encender arduino -> conectar a marlin→ enviar comando Gcode con diferentes RPM → detener | 1. Conectar el arduino y colocarle la RAMPS 1.4 (Se alimenta con 12V) 2. Conectar el motor (NEMA 23) al driver DM556 según sus bobinas (El driver se alimenta con 24V) 3. Conectar el driver (DRV8825) y el motor (NEMA 17) según sus bobinas a la RAMPS. 4. Conectar la salida de las señales de la RAMPS a las entradas negativas del driver ( PLS -, DIR -, EN -) y las salidas positivas a los 5v entregados por el arduino ( PLS -, DIR -, EN -) 5.Conectar la RAMPS a Pronterface teniendo en cuenta el Baud Rate que se configuró en Marlin 6.Subir un G-Code a pronterface en el que se vayan moviendo los motores a distintas posiciones y en cada posición se tenga una velocidad diferente a las anteriores. | El motor cambia de velocidad sin apagarse | Logramos mover el motor a una velocidad desde 0 rpm a 75 rpm segun los valores obtenidos en el algoritmo de pintura
T4 | Prueba de movimiento en grados - Tercer motor | Ensamblar sistema mecanico -> conectar componentes -> encender arduino -> conectar a marlin→ enviar comando Gcode → detener | 1. Conectar el arduino y colocarle la RAMPS 1.4 (Se alimenta con 12V). 2. Conectar el driver (DRV8825) y el motor (NEMA 17) según sus bobinas a la RAMPS. 3.Conectar la RAMPS a Pronterface teniendo en cuenta el Baud Rate que se configuró en Marlin. 4.Enviar comando serial de G-Code desde Pronterface para activar el motor (M17), para configurarlo como coordenadas absolutas (G90) y por ultimo para probar un movimiento a una velocidad especificada teniendo en cuenta que cada valor equivale a 1 grado (ej: G1 E20 F200). | El eje se mueve sin atascarse | Logramos mover el motor a un angulo de 180 grados y devolverlo a 0 grados
T5 | Prueba de estabilidad de la estructura - Conjunto mecánico | Ensamblar plataforma -> conectar componentes -> encender arduino -> conectar a marlin→ activar motores → detener | 1. Ensamblar la plataorma de movimiento 2. Conectar el arduino y colocarle la RAMPS 1.4 (Se alimenta con 12V) 3. Conectar el motor (NEMA 23) al driver DM556 según sus bobinas (El driver se alimenta con 24V) 4. Conectar el driver (DRV8825) y el motor (NEMA 17) según sus bobinas a la RAMPS. 5. Conectar la salida de las señales de la RAMPS a las entradas negativas del driver ( PLS -, DIR -, EN -) y las salidas positivas a los 5v entregados por el arduino ( PLS -, DIR -, EN -) 6.Conectar la RAMPS a Pronterface teniendo en cuenta el Baud Rate que se configuró en Marlin 7. Enviar comando de Gcode para activar todos los motores. 8. Evaluar las vibraciones y las tolerancias del mecanismo final. | No se observan vibraciones que afecten la integridad del sistema mecanico | Se ensamblo la plataforma de movimiento y se realizaron las conexiones de los motores y se activaron todos de forma consecutiva, se evidenciaron bastantes vibraciones pero se tomaron medidas para disminuirlas
T6 | Prueba de límites / fin de carrera - Ejes principales | Conectar componentes -> encender arduino -> conectar a marlin→ enviar comando Gcode -> activacion de microswitches → detener | "1. Conectar el arduino y colocarle la RAMPS 1.4 (Se alimenta con 12V) 2. Conectar el motor (NEMA 23) al driver DM556 según sus bobinas (El driver se alimenta con 24V) 3. Conectar el driver (DRV8825) y el motor (NEMA 17) según sus bobinas a la RAMPS. 4. Conectar la salida de las señales de la RAMPS a las entradas negativas del driver ( PLS -, DIR -, EN -) y las salidas positivas a los 5v entregados por el arduino ( PLS -, DIR -, EN -) 5.Conectar los microswitches a la RAMPS 1.4 6.Conectar la RAMPS a Pronterface teniendo en cuenta el Baud Rate que se configuró en Marlin 7.Subir un G-Code a pronterface el cual contenga un perfil de movimiento dentro de los limites establecidos por software ." | El sistema se detiene cuando llega al límite | Se conecto y se realizo una secuencia de movimiento hacia los extremos de la guia, el carro presiono los microswitch de forma correcta, apagando el sistema como método de seguridad
T12 | Prueba del botón de parado de emergencia | Subir codigo a la ESP32 → Conectar los motores → Ejecutar un comando → Oprimir el boton de parado de emergencia | 1. Abrir Pronterface 2. Conectar RAMPS y Arduino 3. Inicializar Gcode y enviar valor de giro 4. Conectar Osciloscopio y medir valor de salida | Las funciones principales responden | Se conecto el Arduino mega con la Ramps y el software Marlin, se envio un comando simulando la conexión de un motor y se midio la salida del driver, el cual dio un funcionamiento correcto
T12 | Prueba de posiciones "Home" sin estructura mecanica | Subir códigos → Conectar motores → Conectar microswiches → Ejecutar Gcode → Oprimir microswiches | 1. Subir y compilar códigos en el Arduino Mega y ESP32 2. Realizar las conexiones de todos los motores 3. Conectar los swiches a la RAMPS 4. Ejecutar el comando de posicionamiento al "Home" 5. Motores avanzan 6. Se oprimen los microswiches manualmente 7. Los motores se detienen y se establece la posición como cero | Los motores se tenienen y se establace el 0 cuando se oprime el microswich | Se subieron los códigos y se hicieron las conexiones de los motores, luego se escribio el comando Gcode de "Home" para cada eje, los motores comenzaron a girar hasta que se oprimio el microswich, los motores se detuvieron y se establecio el 0 en esa posición
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

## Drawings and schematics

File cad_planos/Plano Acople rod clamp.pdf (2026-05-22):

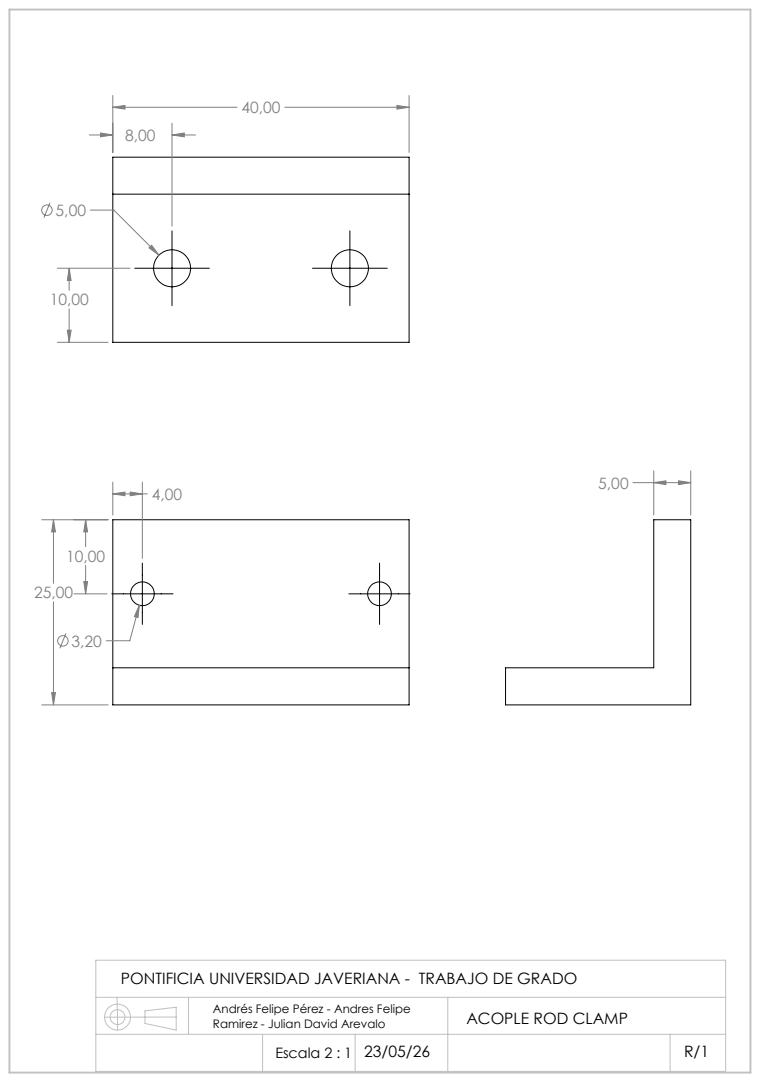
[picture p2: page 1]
Ramirez - Julian David Arevalo; ACOPLE ROD CLAMP; Escala 2 : 1 23/05/26

PONTIFICIA UNIVERSIDAD JAVERIANA - TRABAJO DE GRADO

Andrés Felipe Pérez - Andres Felipe

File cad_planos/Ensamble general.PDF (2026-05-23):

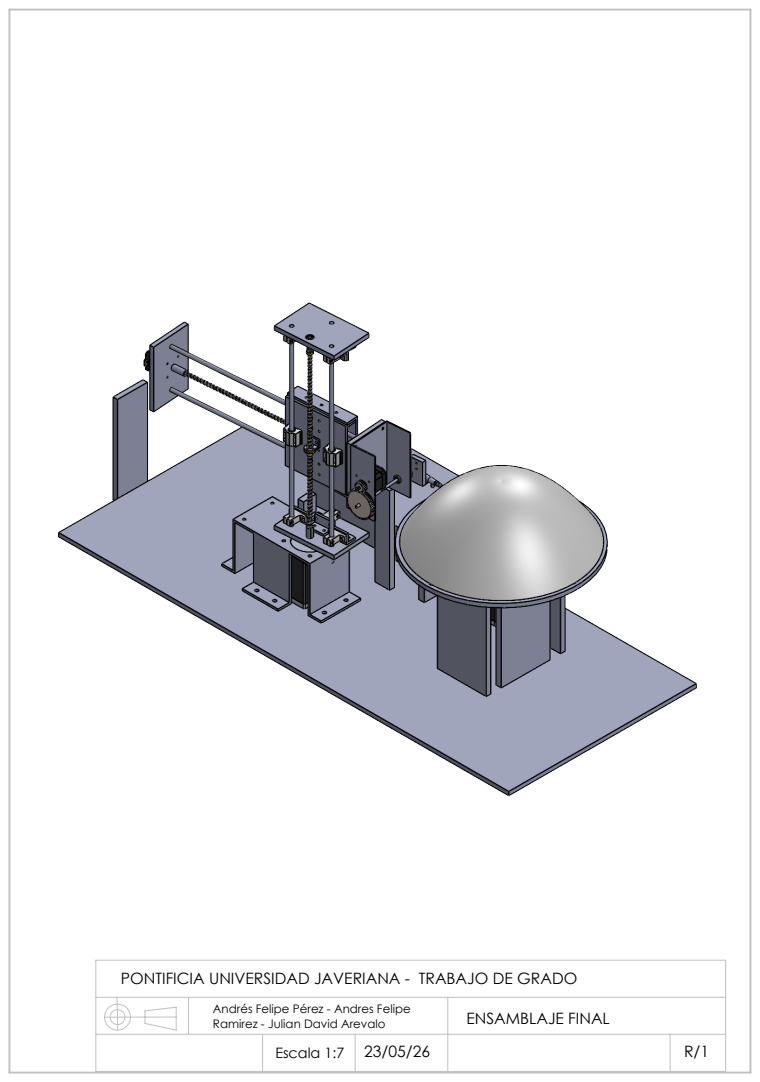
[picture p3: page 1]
Ramirez - Julian David Arevalo; ENSAMBLAJE FINAL; Escala 1:7 23/05/26

PONTIFICIA UNIVERSIDAD JAVERIANA - TRABAJO DE GRADO

Andrés Felipe Pérez - Andres Felipe

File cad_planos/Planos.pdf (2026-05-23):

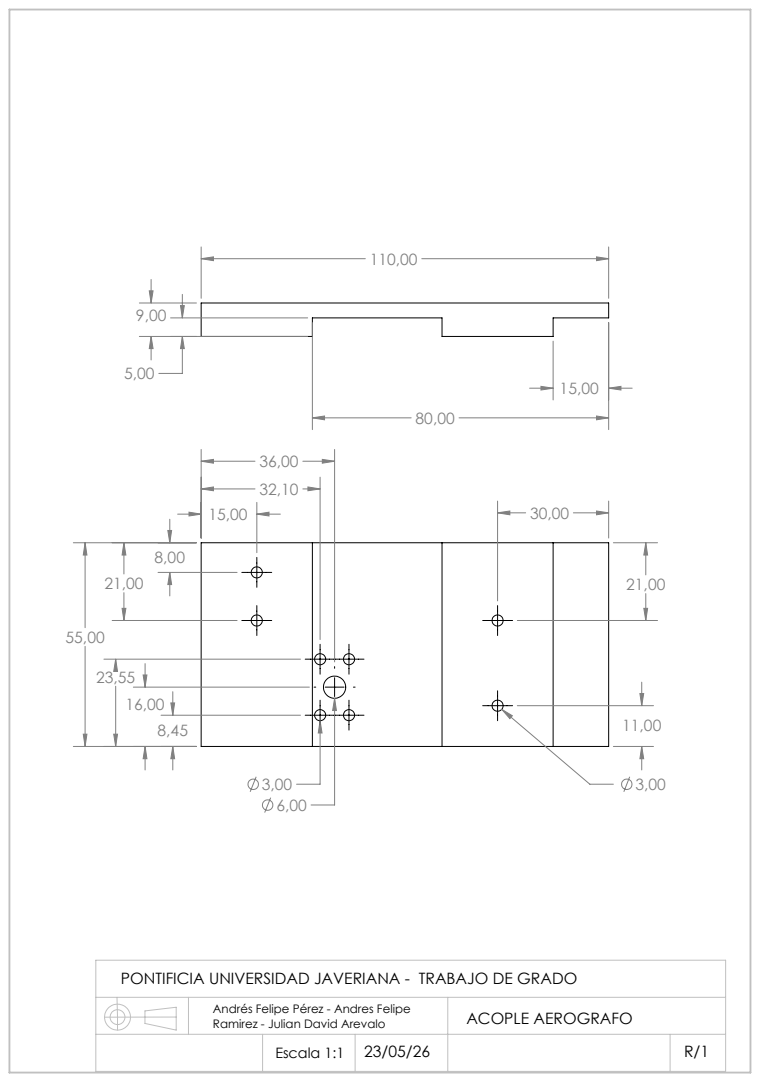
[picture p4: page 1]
Ramirez - Julian David Arevalo; ACOPLE AEROGRAFO; Escala 1:1 23/05/26

PONTIFICIA UNIVERSIDAD JAVERIANA - TRABAJO DE GRADO

Andrés Felipe Pérez - Andres Felipe

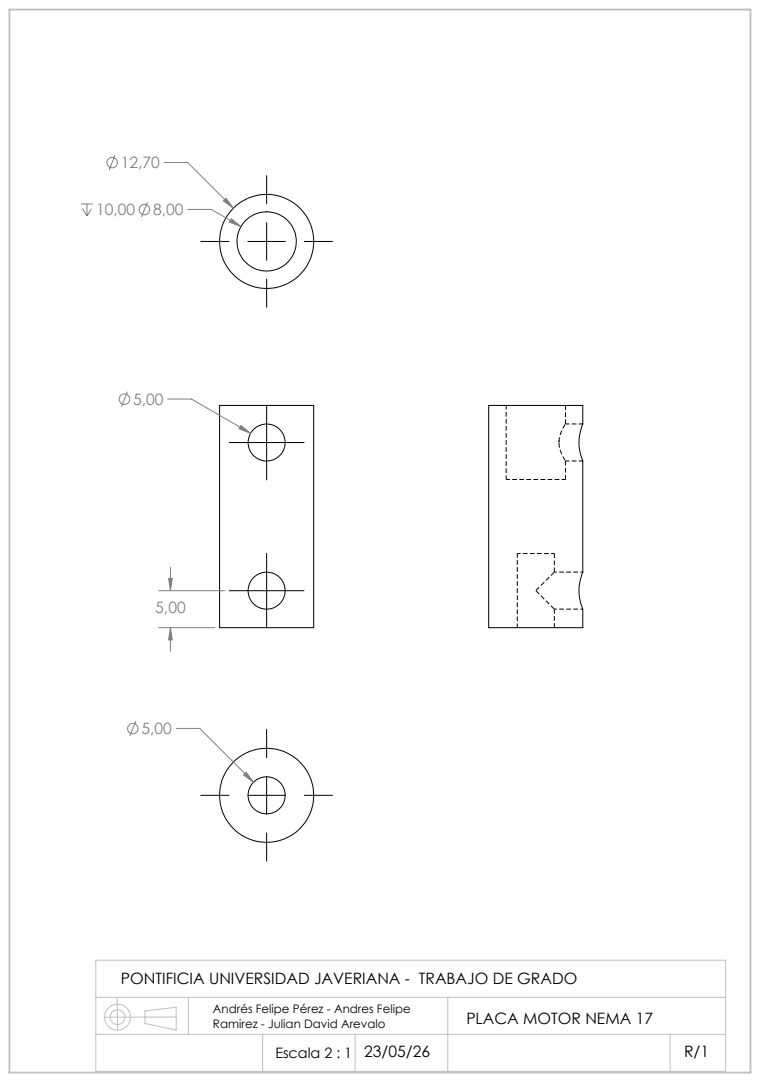
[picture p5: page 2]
Ramirez - Julian David Arevalo; PLACA MOTOR NEMA 17; Escala 2 : 1 23/05/26

PONTIFICIA UNIVERSIDAD JAVERIANA - TRABAJO DE GRADO

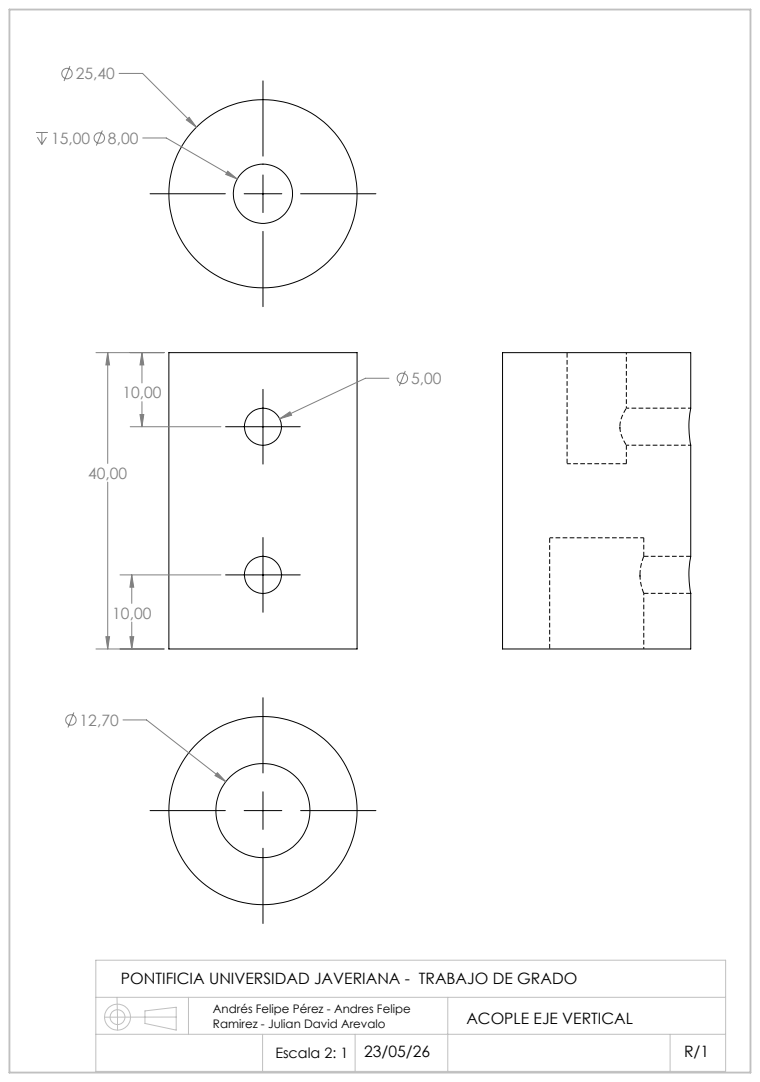
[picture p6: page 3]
Ramirez - Julian David Arevalo; ACOPLE EJE VERTICAL; Escala 2: 1 23/05/26

PONTIFICIA UNIVERSIDAD JAVERIANA - TRABAJO DE GRADO

Ramirez - Julian David Arevalo; ACOPLE ROD CLAMP; Escala 2 : 1 23/05/26

PONTIFICIA UNIVERSIDAD JAVERIANA - TRABAJO DE GRADO

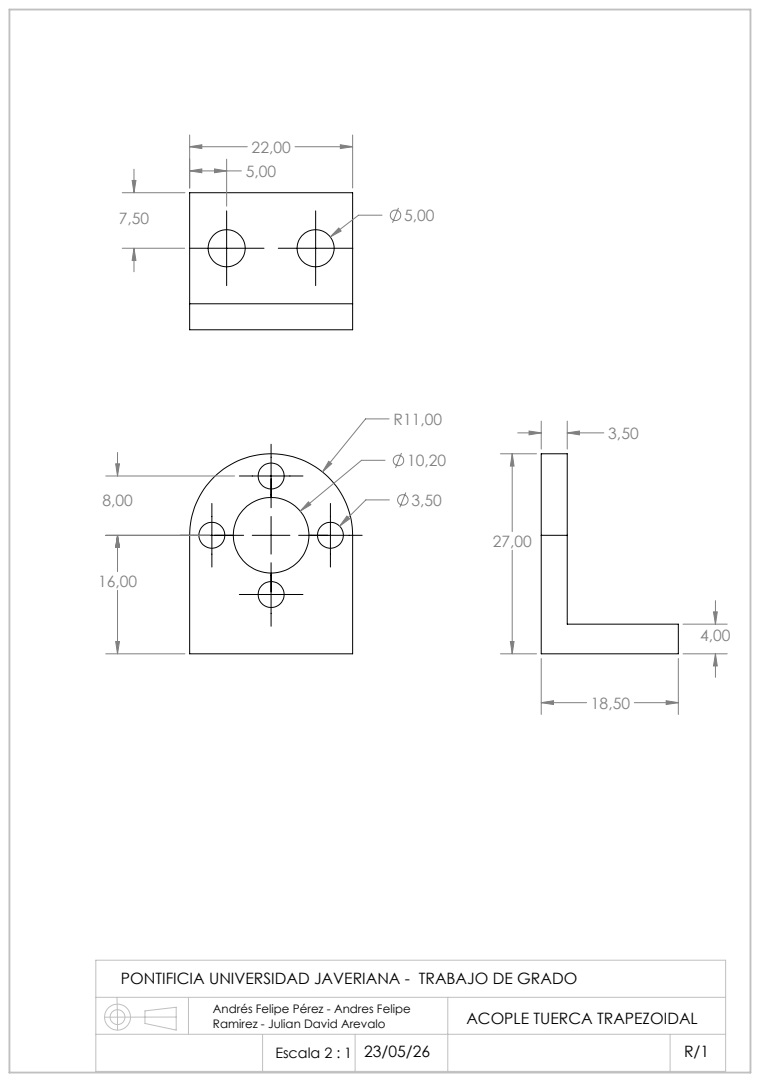
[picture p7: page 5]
Ramirez - Julian David Arevalo; ACOPLE TUERCA TRAPEZOIDAL; Escala 2 : 1 23/05/26

PONTIFICIA UNIVERSIDAD JAVERIANA - TRABAJO DE GRADO

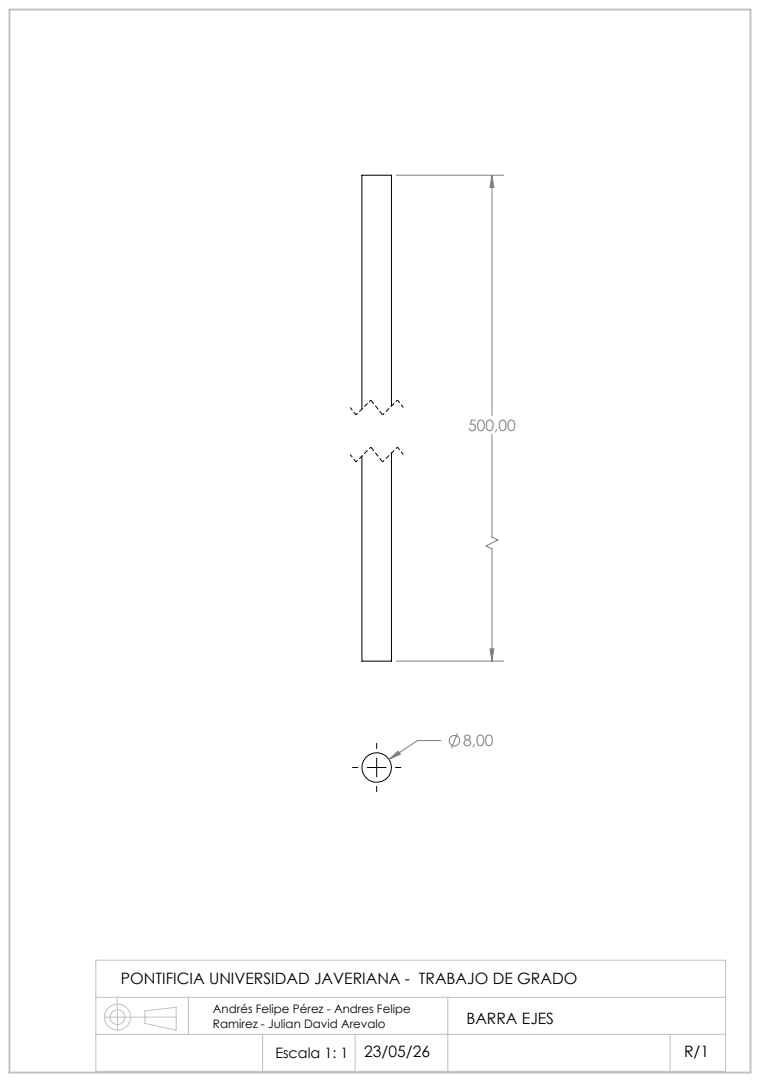
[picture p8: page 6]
Ramirez - Julian David Arevalo; BARRA EJES; Escala 1: 1 23/05/26

PONTIFICIA UNIVERSIDAD JAVERIANA - TRABAJO DE GRADO

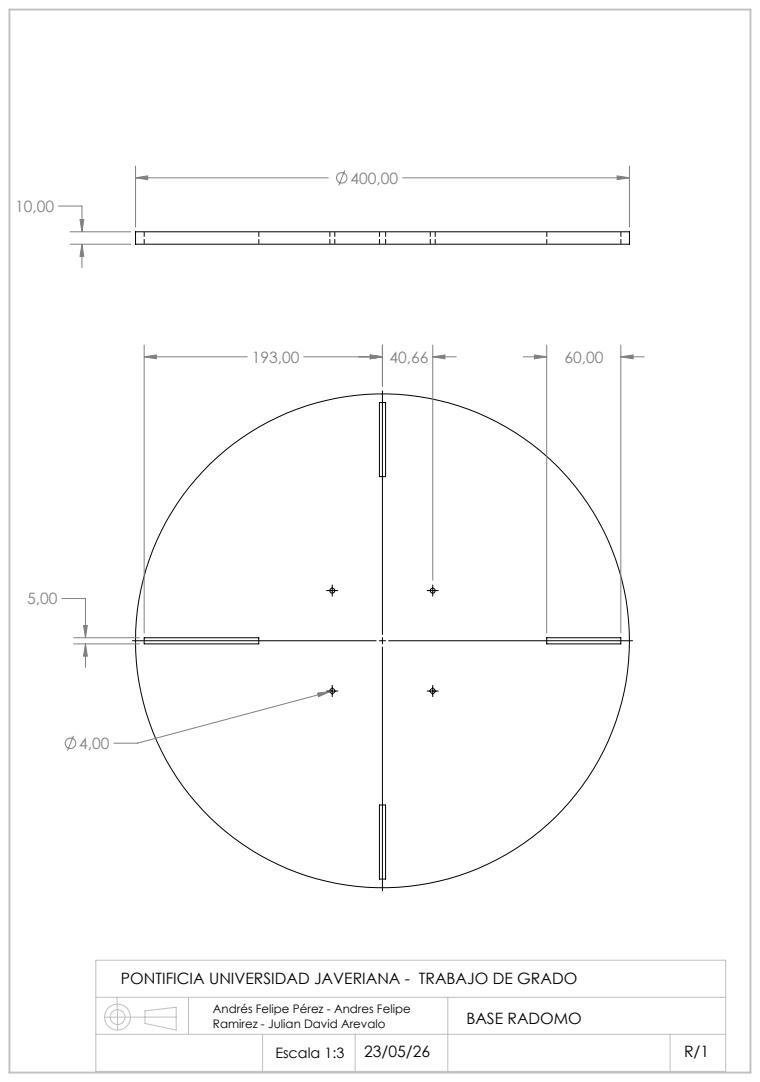
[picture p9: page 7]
Ramirez - Julian David Arevalo; BASE RADOMO; Escala 1:3 23/05/26

PONTIFICIA UNIVERSIDAD JAVERIANA - TRABAJO DE GRADO

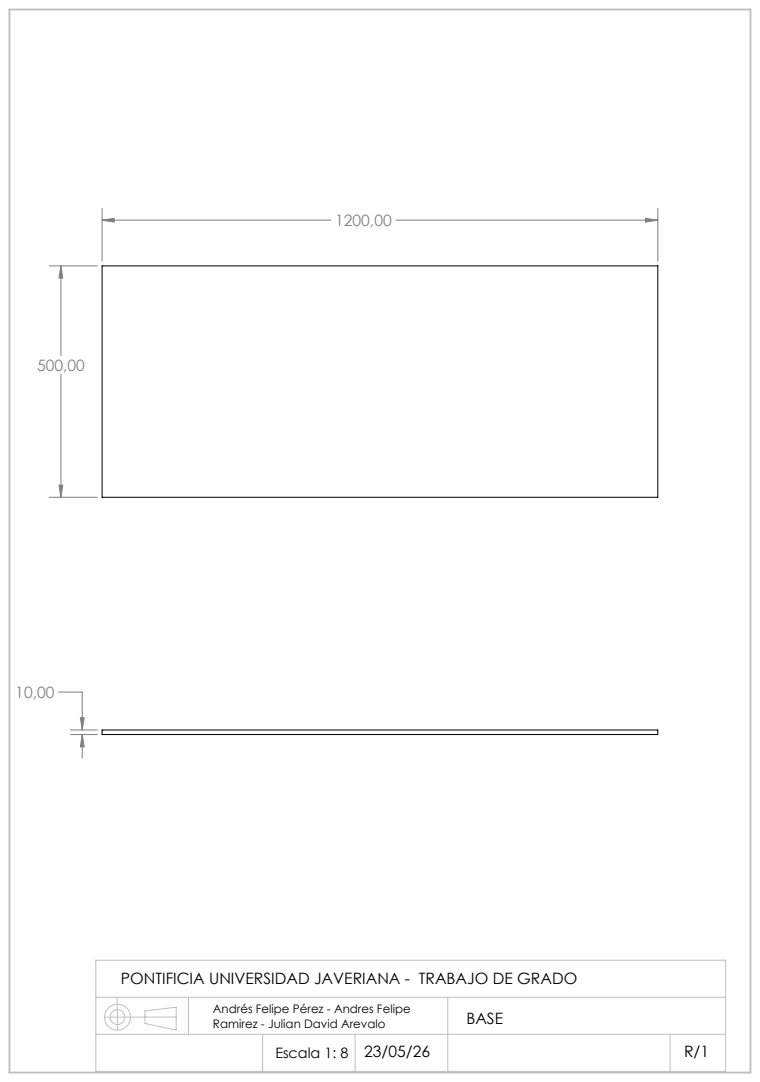
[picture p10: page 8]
Ramirez - Julian David Arevalo; BASE; Escala 1: 8 23/05/26

PONTIFICIA UNIVERSIDAD JAVERIANA - TRABAJO DE GRADO

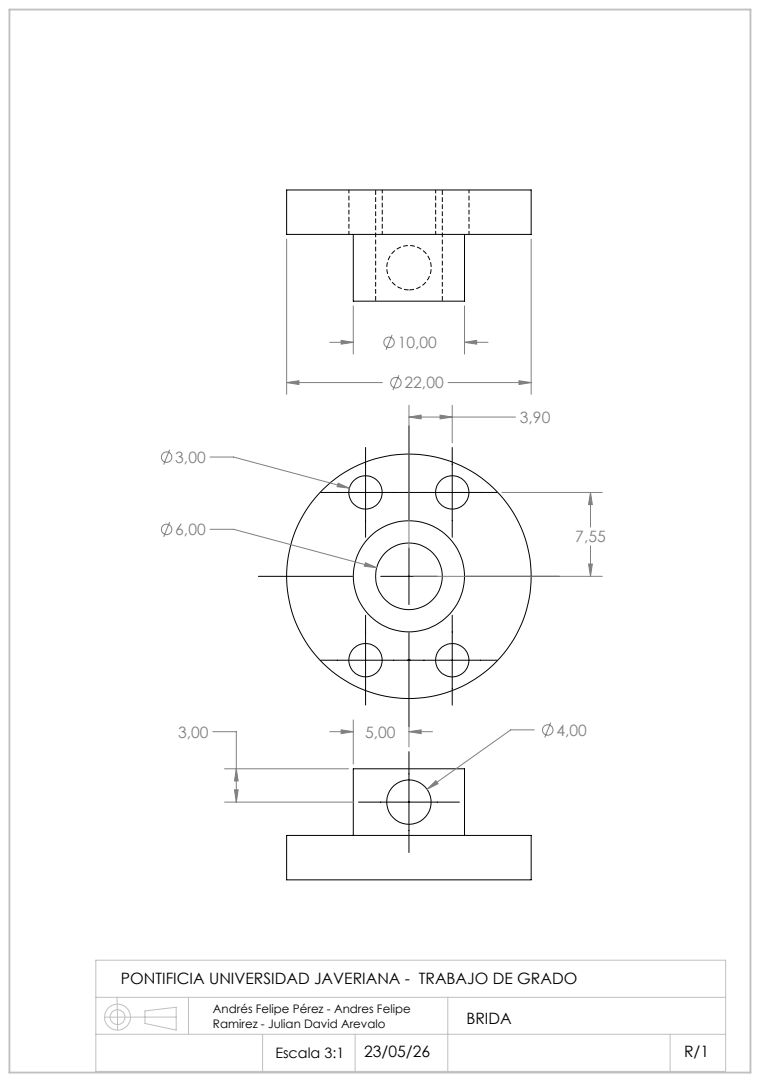
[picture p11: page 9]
Ramirez - Julian David Arevalo; BRIDA; Escala 3:1 23/05/26

PONTIFICIA UNIVERSIDAD JAVERIANA - TRABAJO DE GRADO

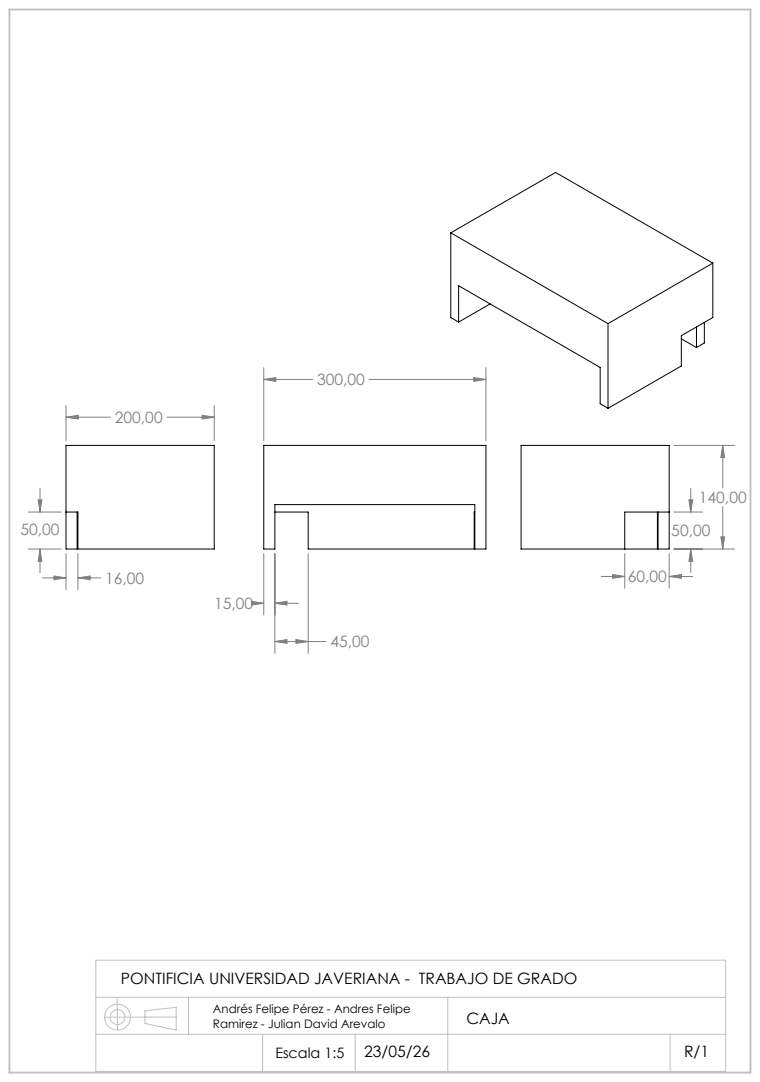
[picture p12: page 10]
Ramirez - Julian David Arevalo; CAJA; Escala 1:5 23/05/26

PONTIFICIA UNIVERSIDAD JAVERIANA - TRABAJO DE GRADO

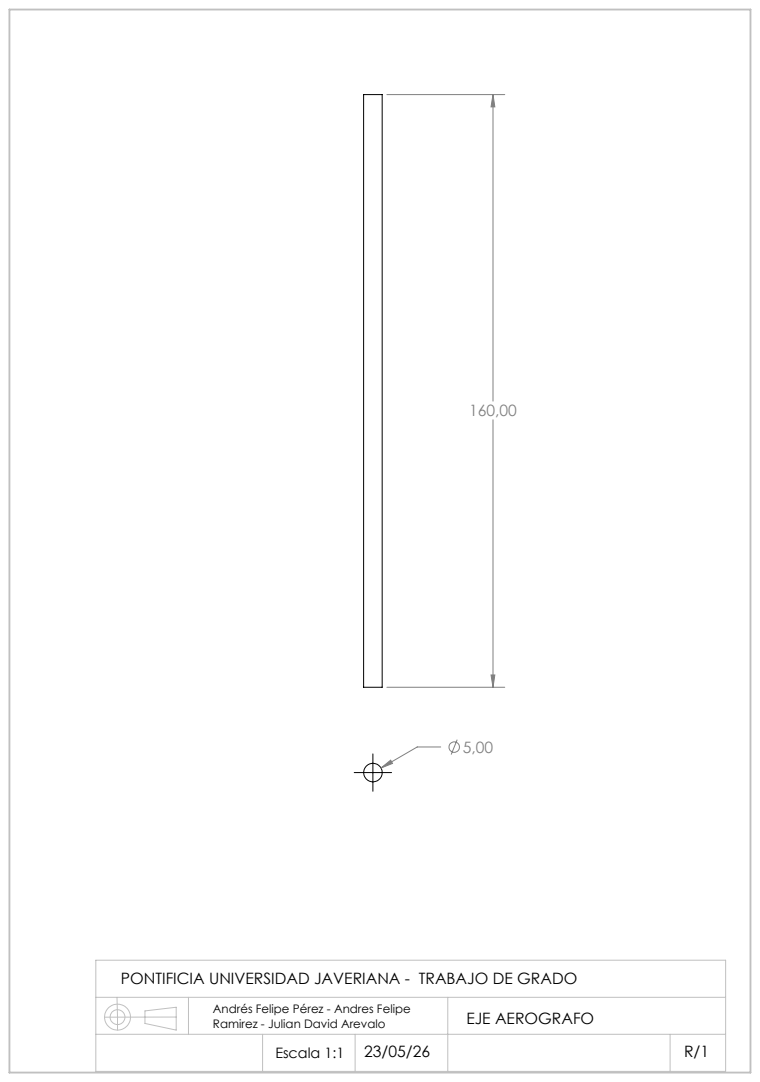
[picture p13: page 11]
Ramirez - Julian David Arevalo; EJE AEROGRAFO; Escala 1:1 23/05/26

PONTIFICIA UNIVERSIDAD JAVERIANA - TRABAJO DE GRADO

Ramirez - Julian David Arevalo; PLACA AEROGRAFO; Escala 1:2 23/05/26

PONTIFICIA UNIVERSIDAD JAVERIANA - TRABAJO DE GRADO

Ramirez - Julian David Arevalo; PLACA CENTRAL 1; Escala 1 : 2 23/05/26

PONTIFICIA UNIVERSIDAD JAVERIANA - TRABAJO DE GRADO

Ramirez - Julian David Arevalo; PLACA CENTRAL 2; Escala 1 : 2 23/05/26

PONTIFICIA UNIVERSIDAD JAVERIANA - TRABAJO DE GRADO

Ramirez - Julian David Arevalo; PLACA MOTOR NEMA 17; Escala 1 : 1 23/05/26

PONTIFICIA UNIVERSIDAD JAVERIANA - TRABAJO DE GRADO

Ramirez - Julian David Arevalo; SOPORTE INFERIOR; Escala 1: 1 23/05/26

PONTIFICIA UNIVERSIDAD JAVERIANA - TRABAJO DE GRADO

Ramirez - Julian David Arevalo; SOPORTE VERTICAL; Escala 1:4 23/05/26

PONTIFICIA UNIVERSIDAD JAVERIANA - TRABAJO DE GRADO

Ramirez - Julian David Arevalo; TABLA MICROSWITCH X; Escala 1:2 23/05/26

PONTIFICIA UNIVERSIDAD JAVERIANA - TRABAJO DE GRADO

Ramirez - Julian David Arevalo; TABLA MICROSWITCH Y; Escala 2:1 23/05/26

PONTIFICIA UNIVERSIDAD JAVERIANA - TRABAJO DE GRADO

Ramirez - Julian David Arevalo; TABLA MICROSWITCH Z; Escala 1:2 23/05/26

PONTIFICIA UNIVERSIDAD JAVERIANA - TRABAJO DE GRADO

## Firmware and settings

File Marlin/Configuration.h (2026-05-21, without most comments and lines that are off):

#pragma once
#define CONFIGURATION_H_VERSION 02010300
#define STRING_CONFIG_H_AUTHOR "(MarlinFirmware)" // Original author or contributor.
  #define MOTHERBOARD BOARD_RAMPS_14_EFB
#define SERIAL_PORT 0
#define BAUDRATE 250000
#define X_DRIVER_TYPE  DRV8825
#define Y_DRIVER_TYPE  DRV8825
#define Z_DRIVER_TYPE  DRV8825
#define E0_DRIVER_TYPE DRV8825
#define EXTRUDERS 1
#define DEFAULT_NOMINAL_FILAMENT_DIA 1.75
#define TEMP_SENSOR_0 1
#define TEMP_SENSOR_1 0
#define TEMP_SENSOR_2 0
#define TEMP_SENSOR_3 0
#define TEMP_SENSOR_4 0
#define TEMP_SENSOR_5 0
#define TEMP_SENSOR_6 0
#define TEMP_SENSOR_7 0
#define TEMP_SENSOR_BED 1
#define TEMP_SENSOR_PROBE 0
#define TEMP_SENSOR_CHAMBER 0
#define TEMP_SENSOR_COOLER 0
#define TEMP_SENSOR_BOARD 0
#define TEMP_SENSOR_SOC 0
#define TEMP_SENSOR_REDUNDANT 0
#define DUMMY_THERMISTOR_998_VALUE  25
#define DUMMY_THERMISTOR_999_VALUE 100
#if TEMP_SENSOR_IS_MAX_TC(0)
  #define MAX31865_SENSOR_OHMS_0      100 // (Ω) Typically 100 or 1000 (PT100 or PT1000)
  #define MAX31865_CALIBRATION_OHMS_0 430 // (Ω) Typically 430 for Adafruit PT100; 4300 for Adafruit PT1000
#endif
#if TEMP_SENSOR_IS_MAX_TC(1)
  #define MAX31865_SENSOR_OHMS_1      100
  #define MAX31865_CALIBRATION_OHMS_1 430
#endif
#if TEMP_SENSOR_IS_MAX_TC(2)
  #define MAX31865_SENSOR_OHMS_2      100
  #define MAX31865_CALIBRATION_OHMS_2 430
#endif
#if TEMP_SENSOR_IS_MAX_TC(BED)
  #define MAX31865_SENSOR_OHMS_BED      100
  #define MAX31865_CALIBRATION_OHMS_BED 430
#endif
#if HAS_E_TEMP_SENSOR
  #define TEMP_RESIDENCY_TIME         10  // (seconds) Time to wait for hotend to "settle" in M109
  #define TEMP_WINDOW                  1  // (°C) Temperature proximity for the "temperature reached" timer
  #define TEMP_HYSTERESIS              3  // (°C) Temperature proximity considered "close enough" to the target
#endif
#if TEMP_SENSOR_BED
  #define TEMP_BED_RESIDENCY_TIME     10  // (seconds) Time to wait for bed to "settle" in M190
  #define TEMP_BED_WINDOW              1  // (°C) Temperature proximity for the "temperature reached" timer
  #define TEMP_BED_HYSTERESIS          3  // (°C) Temperature proximity considered "close enough" to the target
#endif
#if TEMP_SENSOR_CHAMBER
  #define TEMP_CHAMBER_RESIDENCY_TIME 10  // (seconds) Time to wait for chamber to "settle" in M191
  #define TEMP_CHAMBER_WINDOW          1  // (°C) Temperature proximity for the "temperature reached" timer
  #define TEMP_CHAMBER_HYSTERESIS      3  // (°C) Temperature proximity considered "close enough" to the target
#endif
#if TEMP_SENSOR_REDUNDANT
  #define TEMP_SENSOR_REDUNDANT_SOURCE    E1  // The sensor that will provide the redundant reading.
  #define TEMP_SENSOR_REDUNDANT_TARGET    E0  // The sensor that we are providing a redundant reading for.
  #define TEMP_SENSOR_REDUNDANT_MAX_DIFF  10  // (°C) Temperature difference that will trigger a print abort.
#endif
#define HEATER_0_MINTEMP   5
#define HEATER_1_MINTEMP   5
#define HEATER_2_MINTEMP   5
#define HEATER_3_MINTEMP   5
#define HEATER_4_MINTEMP   5
#define HEATER_5_MINTEMP   5
#define HEATER_6_MINTEMP   5
#define HEATER_7_MINTEMP   5
#define BED_MINTEMP        5
#define CHAMBER_MINTEMP    5
#define HEATER_0_MAXTEMP 275
#define HEATER_1_MAXTEMP 275
#define HEATER_2_MAXTEMP 275
#define HEATER_3_MAXTEMP 275
#define HEATER_4_MAXTEMP 275
#define HEATER_5_MAXTEMP 275
#define HEATER_6_MAXTEMP 275
#define HEATER_7_MAXTEMP 275
#define BED_MAXTEMP      150
#define CHAMBER_MAXTEMP  60
#define HOTEND_OVERSHOOT 15   // (°C) Forbid temperatures over MAXTEMP - OVERSHOOT
#define BED_OVERSHOOT    10   // (°C) Forbid temperatures over MAXTEMP - OVERSHOOT
#define COOLER_OVERSHOOT  2   // (°C) Forbid temperatures closer than OVERSHOOT
#define PIDTEMP           // See the PID Tuning Guide at https://reprap.org/wiki/PID_Tuning
#define PID_MAX  255      // Limit hotend current while PID is active (see PID_FUNCTIONAL_RANGE below); 255=full current
#define PID_K1     0.95   // Smoothing factor within any PID loop
    #define DEFAULT_KP  22.20
    #define DEFAULT_KI   1.08
    #define DEFAULT_KD 114.00
#define MAX_BED_POWER 255 // limits duty cycle to bed; 255=full current
#define MAX_CHAMBER_POWER 255 // limits duty cycle to chamber heater; 255=full current
  #define PID_FUNCTIONAL_RANGE 20 // If the temperature difference between the target temperature and the actual temperature
#define EXTRUDE_MINTEMP 170
#define PREVENT_LENGTHY_EXTRUDE
#define EXTRUDE_MAXLENGTH 200
#define THERMAL_PROTECTION_HOTENDS // Enable thermal protection for all extruders
#define THERMAL_PROTECTION_BED     // Enable thermal protection for the heated bed
#define THERMAL_PROTECTION_CHAMBER // Enable thermal protection for the heated chamber
#define THERMAL_PROTECTION_COOLER  // Enable thermal protection for the laser cooling
#define ENDSTOPPULLUPS
#define X_MIN_ENDSTOP_HIT_STATE HIGH
#define X_MAX_ENDSTOP_HIT_STATE HIGH
#define Y_MIN_ENDSTOP_HIT_STATE HIGH
#define Y_MAX_ENDSTOP_HIT_STATE HIGH
#define Z_MIN_ENDSTOP_HIT_STATE HIGH
#define Z_MAX_ENDSTOP_HIT_STATE HIGH
#define I_MIN_ENDSTOP_HIT_STATE HIGH
#define I_MAX_ENDSTOP_HIT_STATE HIGH
#define J_MIN_ENDSTOP_HIT_STATE HIGH
#define J_MAX_ENDSTOP_HIT_STATE HIGH
#define K_MIN_ENDSTOP_HIT_STATE HIGH
#define K_MAX_ENDSTOP_HIT_STATE HIGH
#define U_MIN_ENDSTOP_HIT_STATE HIGH
#define U_MAX_ENDSTOP_HIT_STATE HIGH
#define V_MIN_ENDSTOP_HIT_STATE HIGH
#define V_MAX_ENDSTOP_HIT_STATE HIGH
#define W_MIN_ENDSTOP_HIT_STATE HIGH
#define W_MAX_ENDSTOP_HIT_STATE HIGH
#define Z_MIN_PROBE_ENDSTOP_HIT_STATE HIGH
#define DIRECT_PIN_CONTROL
#define DEFAULT_AXIS_STEPS_PER_UNIT   { 80, 80, 1.7 , 80 }
#define EDITABLE_STEPS_PER_UNIT
#define DEFAULT_MAX_FEEDRATE          { 300, 300, 5, 25 }
#define DEFAULT_MAX_ACCELERATION      { 3000, 3000, 100, 10000 }
#define DEFAULT_ACCELERATION          3000    // X, Y, Z and E acceleration for printing moves
#define DEFAULT_RETRACT_ACCELERATION  3000    // E acceleration for retracts
#define DEFAULT_TRAVEL_ACCELERATION   3000    // X, Y, Z acceleration for travel (non printing) moves
  #define JUNCTION_DEVIATION_MM 0.013 // (mm) Distance from real junction edge
  #define JD_HANDLE_SMALL_SEGMENTS    // Use curvature estimation instead of just the junction angle
#define Z_MIN_PROBE_USES_Z_MIN_ENDSTOP_PIN
#define NOZZLE_TO_PROBE_OFFSET { 10, 10, 0 } // (mm) X, Y, Z distance from Nozzle tip to Probe trigger-point
#define PROBING_TOOL 0
#define PROBING_MARGIN 10
#define XY_PROBE_FEEDRATE    (133*60) // (mm/min)
#define Z_PROBE_FEEDRATE_FAST  (4*60) // (mm/min)
#define Z_PROBE_FEEDRATE_SLOW (Z_PROBE_FEEDRATE_FAST / 2) // (mm/min)
#define Z_CLEARANCE_DEPLOY_PROBE   10 // (mm) Z Clearance for Deploy/Stow
#define Z_CLEARANCE_BETWEEN_PROBES  5 // (mm) Z Clearance between probe points
#define Z_CLEARANCE_MULTI_PROBE     5 // (mm) Z Clearance between multiple probes
#define Z_PROBE_ERROR_TOLERANCE     3 // (mm) Tolerance for early trigger (<= -probe.offset.z + ZPET)
#define Z_PROBE_LOW_POINT          -2 // (mm) Farthest distance below the trigger-point to go before stopping
#define X_ENABLE_ON LOW
#define Y_ENABLE_ON LOW
#define Z_ENABLE_ON LOW
#define E_ENABLE_ON LOW // For all extruders
#define DISABLE_OTHER_EXTRUDERS   // Keep only the active extruder enabled
#define INVERT_X_DIR false
#define INVERT_Y_DIR true
#define INVERT_Z_DIR false
#define INVERT_E0_DIR false
#define INVERT_E1_DIR false
#define INVERT_E2_DIR false
#define INVERT_E3_DIR false
#define INVERT_E4_DIR false
#define INVERT_E5_DIR false
#define INVERT_E6_DIR false
#define INVERT_E7_DIR false
#define X_HOME_DIR -1
#define Y_HOME_DIR 1
#define Z_HOME_DIR 1
#define X_BED_SIZE 200
#define Y_BED_SIZE 200
#define X_MIN_POS 0
#define Y_MIN_POS 0
#define Z_MIN_POS 0
#define X_MAX_POS X_BED_SIZE
#define Y_MAX_POS Y_BED_SIZE
#define Z_MAX_POS 200
#define MIN_SOFTWARE_ENDSTOPS
  #define MIN_SOFTWARE_ENDSTOP_X
  #define MIN_SOFTWARE_ENDSTOP_Y
  #define MIN_SOFTWARE_ENDSTOP_Z
  #define MIN_SOFTWARE_ENDSTOP_I
  #define MIN_SOFTWARE_ENDSTOP_J
  #define MIN_SOFTWARE_ENDSTOP_K
  #define MIN_SOFTWARE_ENDSTOP_U
  #define MIN_SOFTWARE_ENDSTOP_V
  #define MIN_SOFTWARE_ENDSTOP_W
#define MAX_SOFTWARE_ENDSTOPS
  #define MAX_SOFTWARE_ENDSTOP_X
  #define MAX_SOFTWARE_ENDSTOP_Y
  #define MAX_SOFTWARE_ENDSTOP_Z
  #define MAX_SOFTWARE_ENDSTOP_I
  #define MAX_SOFTWARE_ENDSTOP_J
  #define MAX_SOFTWARE_ENDSTOP_K
  #define MAX_SOFTWARE_ENDSTOP_U
  #define MAX_SOFTWARE_ENDSTOP_V
  #define MAX_SOFTWARE_ENDSTOP_W
#define HOMING_FEEDRATE_MM_M { (8*60), (8*60), (4*60) }
#define VALIDATE_HOMING_ENDSTOPS
#define EEPROM_CHITCHAT       // Give feedback on EEPROM commands. Disable to save flash.
#define EEPROM_BOOT_SILENT    // Keep M503 quiet and only give errors during first load
#define HOST_KEEPALIVE_FEATURE        // Disable this if your host doesn't like keepalive messages
#define DEFAULT_KEEPALIVE_INTERVAL 2  // Number of seconds between "busy" messages. Set with M113.
#define BUSY_WHILE_HEATING            // Some hosts require "busy" messages even during heating
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

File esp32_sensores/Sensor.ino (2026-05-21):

#include <Arduino.h>
#include <Wire.h>
#include <Adafruit_VL53L0X.h>

// ==========================
// Pines ESP32
// ==========================
static const int PIN_I2C_SDA   = 21;
static const int PIN_I2C_SCL   = 22;
static const int PIN_XSHUT     = 4;    // opcional, solo si lo conectas
static const int PIN_ALARM_OUT = 27;
static const int PIN_LED       = 2;    // LED interno opcional

// Entradas
static const int PIN_BOTON     = 32;   // botón NO
static const int PIN_MICRO_1   = 33;   // microswitch NC
static const int PIN_MICRO_2   = 25;   // microswitch NC

// ==========================
// Parámetros
// ==========================
static const uint16_t DIST_STOP_MM = 55;
static const uint32_t I2C_FREQ_HZ  = 400000;

// Si quieres que un fallo del sensor también active alarma,
// cambia esto a true.
static const bool ALARM_ON_SENSOR_ERROR = false;

// ==========================
// Sensor VL53L0X
// ==========================
Adafruit_VL53L0X lox = Adafruit_VL53L0X();

// ==========================
// Variables
// ==========================
int16_t lastDistanceMm = -1;
uint32_t lastPrintMs = 0;

// --------------------------------------------------
// LOW  = alarma / mandar señal a RAMPS
// HIGH = normal
// --------------------------------------------------
void setAlarmOutput(bool danger)
{
  digitalWrite(PIN_ALARM_OUT, danger ? LOW : HIGH);
  digitalWrite(PIN_LED, danger ? HIGH : LOW);
}

// --------------------------------------------------
// Botón conectado en NO
//
// COM -> GND
// NO  -> GPIO 32
//
// Sin presionar = HIGH
// Presionado    = LOW
// --------------------------------------------------
bool botonPresionado()
{
  return digitalRead(PIN_BOTON) == LOW;
}

// --------------------------------------------------
// Microswitch conectado en NC
//
// COM -> GND
// NC  -> GPIO
//
// En reposo  = LOW
// Presionado = HIGH
// Cable roto = HIGH, también alarma
// --------------------------------------------------
bool microNCPresionado(int pin)
{
  return digitalRead(pin) == HIGH;
}

// --------------------------------------------------
// Lee distancia del VL53L0X
// Devuelve distancia en mm
// Devuelve -1 si no hay lectura válida
// --------------------------------------------------
int16_t readDistanceMm()
{
  VL53L0X_RangingMeasurementData_t measure;

  lox.rangingTest(&measure, false);

  // RangeStatus 4 suele indicar fuera de rango en la librería Adafruit.
  // También descartamos distancia 0.
  if (measure.RangeStatus != 4 && measure.RangeMilliMeter > 0) {
    return (int16_t)measure.RangeMilliMeter;
  }

  return -1;
}

// --------------------------------------------------
// Debug serial
// --------------------------------------------------
void printStatus(
  int16_t distanceMm,
  bool sensorDanger,
  bool boton,
  bool micro1,
  bool micro2,
  bool sensorError
)
{
  uint32_t now = millis();
  if (now - lastPrintMs < 100) return;
  lastPrintMs = now;

  Serial.print("Distancia: ");
  if (distanceMm < 0) {
    Serial.print("sin dato valido");
  } else {
    Serial.print(distanceMm);
    Serial.print(" mm");
  }

  Serial.print(" | sensor=");
  if (sensorError) {
    Serial.print("SIN DATO");
  } else {
    Serial.print(sensorDanger ? "ALARMA" : "OK");
  }

  Serial.print(" | boton_NO=");
  Serial.print(boton ? "PRESIONADO" : "suelto");

  Serial.print(" | micro1_NC=");
  Serial.print(micro1 ? "PRESIONADO/ABIERTO" : "reposo");

  Serial.print(" | micro2_NC=");
  Serial.print(micro2 ? "PRESIONADO/ABIERTO" : "reposo");

  Serial.print(" | salida GPIO27=");
  Serial.println((digitalRead(PIN_ALARM_OUT) == LOW) ? "ALARMA" : "NORMAL");
}

void setup()
{
  pinMode(PIN_ALARM_OUT, OUTPUT);
  pinMode(PIN_LED, OUTPUT);

  pinMode(PIN_BOTON, INPUT_PULLUP);
  pinMode(PIN_MICRO_1, INPUT_PULLUP);
  pinMode(PIN_MICRO_2, INPUT_PULLUP);

  // Estado normal al arrancar
  setAlarmOutput(false);

  Serial.begin(115200);
  delay(300);

  Serial.println();
  Serial.println("Iniciando VL53L0X con ESP32...");

  // I2C del ESP32
  Wire.begin(PIN_I2C_SDA, PIN_I2C_SCL);
  Wire.setClock(I2C_FREQ_HZ);

  // XSHUT es opcional.
  // Si tu módulo VL53L0X no tiene XSHUT conectado, esto no afecta.
  pinMode(PIN_XSHUT, OUTPUT);
  digitalWrite(PIN_XSHUT, LOW);
  delay(10);
  digitalWrite(PIN_XSHUT, HIGH);
  delay(10);

  // Dirección normal del VL53L0X: 0x29
  if (!lox.begin(0x29, false, &Wire)) {
    Serial.println("ERROR: No se detecta el VL53L0X.");
    Serial.println("Revisa SDA, SCL, 3.3V, GND y direccion I2C.");

    // Por seguridad puedes dejarlo en alarma si falla el sensor
    if (ALARM_ON_SENSOR_ERROR) {
      setAlarmOutput(true);
    }

    while (1) {
      delay(100);
    }
  }

  Serial.println("VL53L0X iniciado correctamente.");
  Serial.print("DIST_STOP_MM = ");
  Serial.println(DIST_STOP_MM);
}

void loop()
{
  lastDistanceMm = readDistanceMm();

  bool sensorError = lastDistanceMm < 0;

  bool sensorDanger = false;
  if (lastDistanceMm > 0 && lastDistanceMm <= DIST_STOP_MM) {
    sensorDanger = true;
  }

  bool botonActivo  = botonPresionado();
  bool micro1Activo = microNCPresionado(PIN_MICRO_1);
  bool micro2Activo = microNCPresionado(PIN_MICRO_2);

  // Todos hacen exactamente lo mismo:
  // sensor, botón o microswitch activado => GPIO 27 en LOW
  bool danger = sensorDanger || botonActivo || micro1Activo || micro2Activo;

  if (ALARM_ON_SENSOR_ERROR && sensorError) {
    danger = true;
  }

  setAlarmOutput(danger);

  printStatus(
    lastDistanceMm,
    sensorDanger,
    botonActivo,
    micro1Activo,
    micro2Activo,
    sensorError
  );

  delay(20);
}

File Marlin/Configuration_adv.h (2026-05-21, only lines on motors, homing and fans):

#define E0_AUTO_FAN_PIN -1
#define E1_AUTO_FAN_PIN -1
#define E2_AUTO_FAN_PIN -1
#define E3_AUTO_FAN_PIN -1
#define E4_AUTO_FAN_PIN -1
#define E5_AUTO_FAN_PIN -1
#define E6_AUTO_FAN_PIN -1
#define E7_AUTO_FAN_PIN -1
#define CHAMBER_AUTO_FAN_PIN -1
#define COOLER_AUTO_FAN_PIN -1
#define HOMING_BUMP_MM      { 5, 5, 2 }       // (linear=mm, rotational=°) Backoff from endstops after first bump
#define HOMING_BUMP_DIVISOR { 2, 2, 4 }       // Re-Bump Speed Divisor (Divides the Homing Feedrate)
#define MICROSTEP_MODES { 16, 16, 16, 16, 16, 16 } // [1,2,4,8,16]

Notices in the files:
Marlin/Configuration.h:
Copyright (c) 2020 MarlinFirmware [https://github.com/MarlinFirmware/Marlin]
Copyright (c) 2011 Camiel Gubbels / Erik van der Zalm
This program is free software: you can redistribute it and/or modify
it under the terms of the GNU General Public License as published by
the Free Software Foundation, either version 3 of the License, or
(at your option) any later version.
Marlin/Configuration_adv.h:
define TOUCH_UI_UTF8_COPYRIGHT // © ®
